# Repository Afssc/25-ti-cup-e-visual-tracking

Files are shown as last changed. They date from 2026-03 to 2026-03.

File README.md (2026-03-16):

# 2025 TI杯 E题｜云台视觉跟踪方案

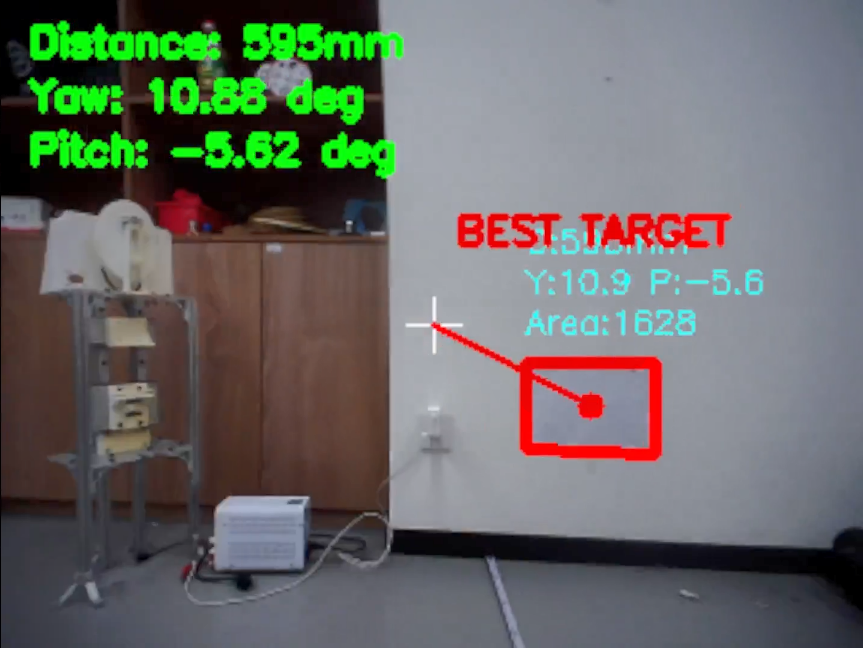
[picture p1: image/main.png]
系统主图


## 1. 系统概述

本项目面向 TI 杯 E 题视觉跟踪场景，采用“嵌入式控制 + 视觉闭环”的一体化方案：

- **主控平台**：Raspberry Pi 4B（树莓派 4B）
- **云台执行机构**：双轴结构，使用 **2 个张大头闭环 42 步进电机**
- **传动结构**：双轴 **4:1 同步带轮减速**（提升分辨率与稳定性）
- **人机交互**：4×4 矩阵按键
	- 外圈 12 个按键：用于方向/视角快速选择
	- 中间 4 个按键：用于赛题功能触发、调试功能、激光开关等

控制逻辑上，按键触发云台预置位或功能回调，视觉环路计算偏差角后驱动双轴步进修正，目标居中后执行激光动作。

---

## 2. 硬件接线说明

项目中接线定义可参考 [key_uart_led.py](key_uart_led.py) 与 [key_array.py](key_array.py)。

### 2.1 LED + 独立按键 + 串口（`key_uart_led.py`）

| 功能 | BCM引脚/设备 | 说明 |
|---|---|---|
| 激光/LED 控制 | GPIO17 | 输出，高电平点亮 |
| KEY1 | GPIO5 | 上拉输入，下降沿触发 |
| KEY2 | GPIO6 | 上拉输入，下降沿触发 |
| 电机串口 | `/dev/ttyUSB0` | 115200 波特率 |

`key_uart_led.py` 的流程为：KEY1 触发回零指令与状态确认，通过后点亮激光；KEY2 直接熄灭激光。

### 2.2 4×4 矩阵按键（`key_array.py`）

矩阵按键采用 8 根 GPIO：

- **行引脚**：GPIO18、23、24、25（输出）
- **列引脚**：GPIO12、16、20、21（输入上拉）

程序通过逐行拉低扫描列输入，带 50ms 消抖逻辑，按键触发后执行映射回调（预置方位、赛题流程、调试、关激光等）。

---

## 3. 视觉算法流程（`cv.py` 中 `cv_loop`）

视觉主流程是“检测矩形目标 → 估距 → 解算角度 → 云台修正 → 命中判定”的闭环控制。

### 3.1 图像预处理

1. 缩放
2. 灰度化 + 高斯滤波
3. 自适应阈值分割（二值化）
4. 提取外轮廓

### 3.2 候选目标筛选

对轮廓依次执行：

- 面积阈值过滤（去噪）
- 多边形逼近（保留 4 边形）
- 凸性判断 + 凸包面积比过滤（提升几何可信度）

### 3.3 中心、距离与角度计算

- **中心点**：优先使用四边形对角线交点法估计目标中心
- **距离估计**：基于两组平行边像素长度，结合目标真实尺寸与视场角，按相似几何计算距离
- **角度解算**：将像素偏差转换为 yaw / pitch 偏差，并乘以增益系数
- **误差补偿**：按距离区间对中心点作经验修正（主要是 y 向修正）

### 3.4 目标选择与控制输出

- 评分策略：综合考虑目标面积与离图像中心距离
- 选择最佳目标后输出 `yaw/pitch`，调用云台运动接口执行修正
- 若像素误差落入容差阈值，则判定对准并点亮激光

该流程在比赛场景下兼顾了识别稳定性与闭环响应速度。
由于角度近似关系，大角度偏差需修正两次，小角度一次到位

---

## 4. 效果展示

### 4.1 云台结构

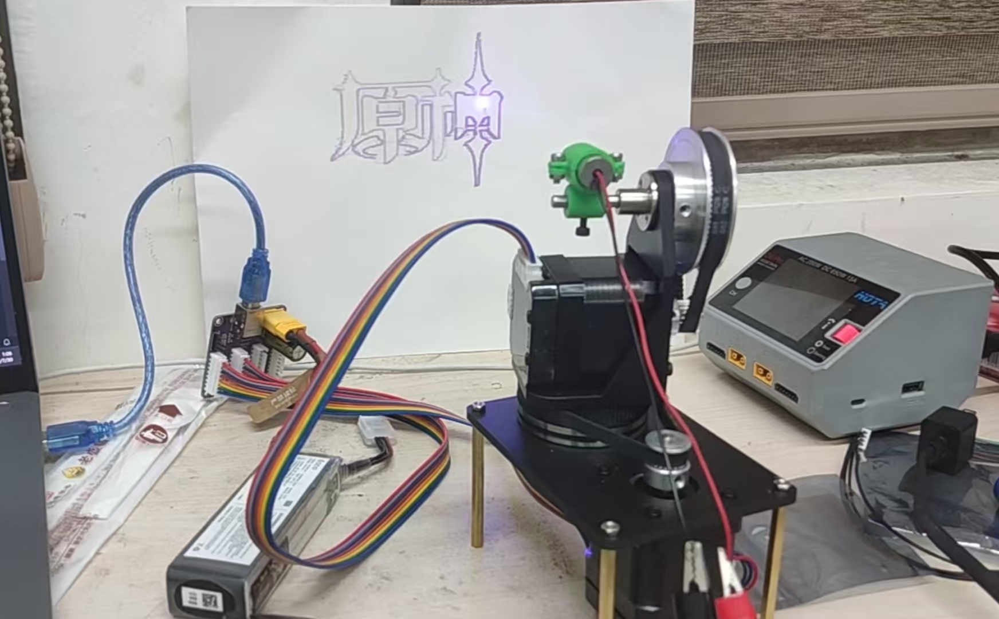
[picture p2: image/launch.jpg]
云台激光绘制展示


### 4.2 鲁棒性

鲁棒性展示

---

## 5. 项目结构与文件说明

```text
.
├── README.md
├── cv.py
├── key_array.py
├── key_callbacks.py
├── key_uart_led.py
├── lazer.py
├── zdt.py
├── image/
│   ├── main.png
│   ├── launch.jpg
│   └── robust.gif
├── stl/
│   ├── 带轮.stl
│   ├── 底板.stl
│   ├── 激光笔支架.stl
│   ├── 激光笔支架盖子.stl
│   ├── 转台.stl
│   └── 转接板.stl
└── test/
		├── a.ipynb
		├── cv.ipynb
		└── led_keys.py
```

### 文件职责说明

- `cv.py`：视觉检测与跟踪主循环（目标检测、估距、角度计算、闭环控制）
- `zdt.py`：张大头闭环步进电机串口协议封装与运动控制
- `lazer.py`：激光 GPIO 控制封装
- `key_array.py`：4×4 矩阵按键扫描、消抖与功能映射入口（主启动脚本）
- `key_callbacks.py`：按键回调函数集合（预置位、赛题动作、调试流程）
- `key_uart_led.py`：独立按键 + 串口状态确认 + 激光开关的接线与流程示例
- `image/`：README 展示图与动态效果图
- `stl/`：云台机械结构模型文件（3D 打印/结构复现）
- `test/`：项目早期验证脚本与实验 Notebook

---

## 6. 使用方式（开机自启动）

建议通过 `systemd` 将 `key_array.py` 配置为开机自动启动。

### 6.1 服务文件示例

在 `/etc/systemd/system/ti_gimbal.service` 新建：

```ini
[Unit]
Description=TI Cup Gimbal Vision Service
After=network.target

[Service]
Type=simple
User=pi
WorkingDirectory=/home/pi/2025TI杯-E题-云台视觉跟踪
ExecStart=/usr/bin/python3 /home/pi/2025TI杯-E题-云台视觉跟踪/key_array.py
Restart=always
RestartSec=2

[Install]
WantedBy=multi-user.target
```

> 若实际用户名、路径、Python 解释器路径不同，请按部署环境修改。

### 6.2 启用与验证

```bash
sudo systemctl daemon-reload
sudo systemctl enable ti_gimbal.service
sudo systemctl start ti_gimbal.service
sudo systemctl status ti_gimbal.service
```

### 6.3 常用维护命令

```bash
sudo systemctl restart ti_gimbal.service
sudo journalctl -u ti_gimbal.service -f
```

---

## 7. 说明

测评当天轮子电机故障，循线分没拿到，云台相关的分都拿了  
最终遗憾省二

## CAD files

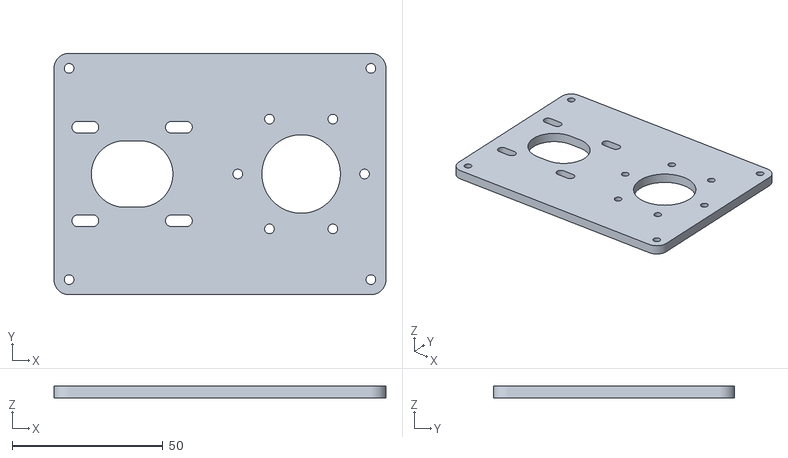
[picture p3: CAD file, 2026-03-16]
stl/底板.stl
110.0 x 80.0 x 4.00

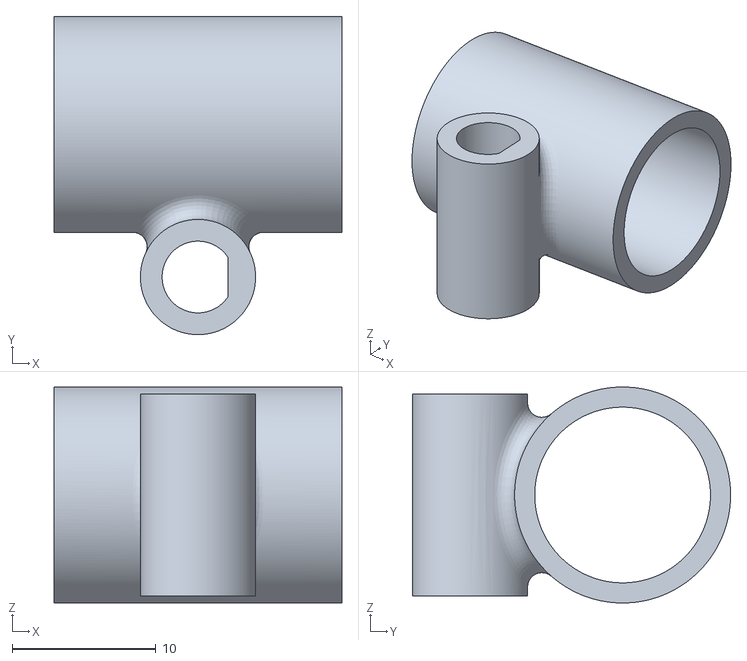
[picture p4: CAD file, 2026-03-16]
stl/激光笔支架.stl
20.0 x 22.1 x 15.0

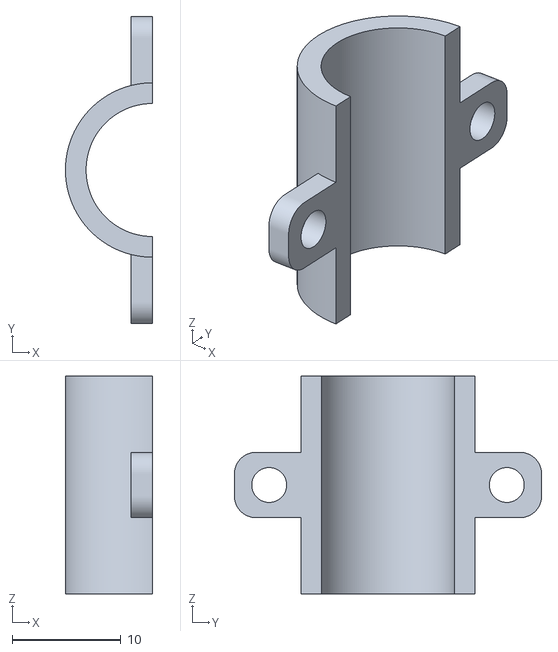
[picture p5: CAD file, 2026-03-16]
stl/激光笔支架盖子.stl
8.00 x 28.2 x 20.0

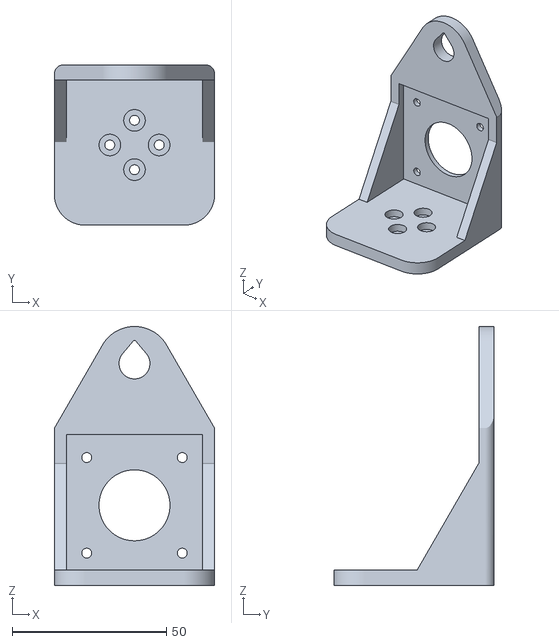
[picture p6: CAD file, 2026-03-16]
stl/转台.stl
52.0 x 52.0 x 84.0

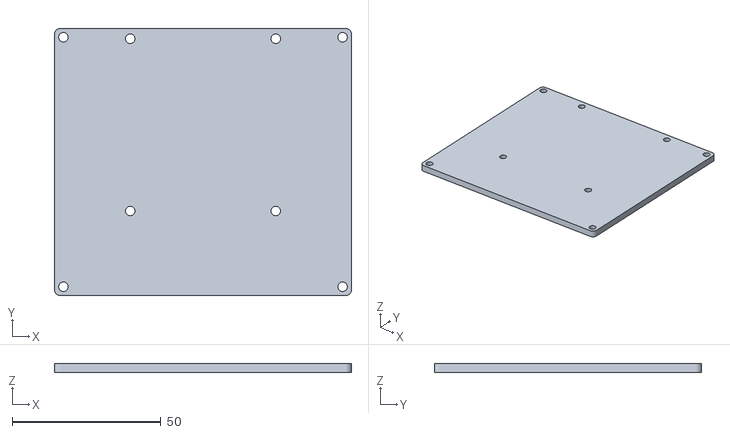
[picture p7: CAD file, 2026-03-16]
stl/转接板.stl
100.0 x 90.0 x 3.00

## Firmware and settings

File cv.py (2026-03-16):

import numpy as np
import cv2
import serial
from zdt import Zdt
from lazer import Lazer


# 暂时没有用到，可以用来把靶环给滤掉

# 云台配置参数
class GimbalConfig():
    def __init__(self,yp_move_callback,lazer_instance:Lazer):
        # 摄像头参数
        self.image_width = 320
        self.image_height = 240
        self.image_center_x = 151
        self.image_center_y = 131
        
        # 摄像头视野角度 (根据你的摄像头规格调整)
        self.camera_fov_horizontal = 90  # 水平视野角度（度）
        self.camera_fov_vertical = 64    # 垂直视野角度（度）
        
        # 已知矩形的实际尺寸 (单位：毫米，根据实际目标调整)
        self.real_rect_width = 315   # 实际矩形宽度
        self.real_rect_height = 225   # 实际矩形高度
        
        # 可以调的增益系数，主要是怕撞云台
        self.yaw_factor = 1.3
        self.pitch_factor = 1.3

        self.yp_move = yp_move_callback
        self.lazer = lazer_instance
        self.tolerance = 0.5
        self.keep_aim = False
        self.debug = False
    
def calculate_gimbal_angles(rect_center_x, rect_center_y, estimated_distance, config):
    """
    计算云台需要旋转的角度来瞄准矩形中心
    
    :param rect_center_x: 矩形中心x坐标
    :param rect_center_y: 矩形中心y坐标
    :param estimated_distance: 估计的目标距离 (毫米)    :param estimated_distance: 估计的目标距离
    :param config: 云台配置对象
    :return: (yaw_angle, pitch_angle) 云台需要旋转的角度（度）
    """
    # 计算像素偏差
    correction_x, correction_y = get_center_correction(estimated_distance)
    correction_x = int(np.round(correction_x,0))
    correction_y = int(np.round(correction_y,0))
    pixel_offset_x = rect_center_x - config.image_center_x + correction_x
    pixel_offset_y = config.image_center_y - rect_center_y + correction_y# 注意y轴方向
    
    # 使用三角函数和实际距离计算角度偏差
    # 首先计算像素偏移对应的实际物理距离
    # 根据相似三角形原理：physical_offset = pixel_offset * (2 * distance * tan(fov/2)) / image_size
    
    # 计算水平方向的实际物理偏移量 (毫米)
    physical_offset_x = pixel_offset_x * (2 * estimated_distance * np.tan(np.radians(config.camera_fov_horizontal / 2))) / config.image_width
    
    # 计算垂直方向的实际物理偏移量 (毫米)
    physical_offset_y = pixel_offset_y * (2 * estimated_distance * np.tan(np.radians(config.camera_fov_vertical / 2))) / config.image_height
    
    # 使用反正切函数计算角度偏差
    yaw_angle = np.degrees(np.arctan(physical_offset_x / estimated_distance))
    pitch_angle = np.degrees(np.arctan(physical_offset_y / estimated_distance))
    
    return yaw_angle, pitch_angle, pixel_offset_x, pixel_offset_y

# def calculate_gimbal_angles(rect_center_x, rect_center_y, estimated_distance, config):
#     """
#     计算云台需要旋转的角度来瞄准矩形中心
    
#     :param rect_center_x: 矩形中心x坐标
#     :param rect_center_y: 矩形中心y坐标
#     :param estimated_distance: 估计的目标距离
#     :param config: 云台配置对象
#     :return: (yaw_angle, pitch_angle) 云台需要旋转的角度（度）
#     """
#     # 计算像素偏差
#     pixel_offset_x = rect_center_x - config.image_center_x
#     pixel_offset_y = config.image_center_y - rect_center_y  # 注意y轴方向
    
#     # 转换为角度偏差
#     yaw_angle = pixel_offset_x / config.pixels_per_degree_x
#     pitch_angle = pixel_offset_y / config.pixels_per_degree_y
    
#     return yaw_angle, pitch_angle

def get_rectangle_center(contour):
    """
    获取矩形的中心点
    
    :param contour: 轮廓点
    :return: (center_x, center_y) 矩形中心坐标
    """
    # 方法1：使用轮廓的矩形边界框
    x, y, w, h = cv2.boundingRect(contour)
    center_x = x + w // 2
    center_y = y + h // 2
    
    # 方法2：使用轮廓的质心（更精确，但受线宽影响）
    # 注意：cv2.moments(contour) 只计算轮廓边界线的矩，不是填充区域的矩
    # 如果轮廓线宽不均匀，质心会偏向较粗的部分
    M = cv2.moments(contour)
    if M["m00"] != 0:
        cx = int(M["m10"] / M["m00"])
        cy = int(M["m01"] / M["m00"])
        return cx, cy
    else:
        return center_x, center_y

def get_rectangle_center_filled(contour, image_shape):
    """
    通过填充轮廓获取真正的几何中心（不受线宽影响）
    
    :param contour: 轮廓点
    :param image_shape: 图像尺寸 (height, width)
    :return: (center_x, center_y) 矩形中心坐标
    """
    # 创建空白掩码
    mask = np.zeros(image_shape, dtype=np.uint8)
    
    # 填充轮廓（修复参数类型）
    cv2.fillPoly(mask, [contour], (255,))
    
    # 计算填充区域的质心
    M = cv2.moments(mask)
    if M["m00"] != 0:
        cx = int(M["m10"] / M["m00"])
        cy = int(M["m01"] / M["m00"])
        return cx, cy
    else:
        # 降级到边界框方法
        x, y, w, h = cv2.boundingRect(contour)
        return x + w // 2, y + h // 2

def get_rectangle_center_diagonal(approx_contour):
    """
    通过计算四边形对角线交点来获取矩形中心
    
    :param approx_contour: 近似的四边形轮廓点 (4个点)
    :return: (center_x, center_y) 矩形中心坐标，如果无法计算则返回None
    """
    
    # 获取四个顶点坐标
    points = approx_contour.reshape(4, 2)
    
    # 找出对角顶点对
    # 方法：计算所有点对之间的距离，最长的两条距离对应两条对角线
    distances = []
    for i in range(4):
        for j in range(i + 1, 4):
            dist = np.sqrt((points[i][0] - points[j][0])**2 + (points[i][1] - points[j][1])**2)
            distances.append((dist, i, j))
    
    # 按距离排序，前两个最长的距离对应两条对角线
    distances.sort(key=lambda x: x[0], reverse=True)
    
    # 获取两条对角线的端点
    diagonal1_p1 = points[distances[0][1]]
    diagonal1_p2 = points[distances[0][2]]
    diagonal2_p1 = points[distances[1][1]]
    diagonal2_p2 = points[distances[1][2]]
    
    # 计算两条对角线的交点
    # 使用直线方程求交点
    def line_intersection(p1, p2, p3, p4):
        """
        计算由点p1-p2和p3-p4构成的两条直线的交点
        """
        x1, y1 = p1[0], p1[1]
        x2, y2 = p2[0], p2[1] 
        x3, y3 = p3[0], p3[1]
        x4, y4 = p4[0], p4[1]
        
        # 计算直线参数
        denom = (x1 - x2) * (y3 - y4) - (y1 - y2) * (x3 - x4)
        
        # 检查平行线
        if abs(denom) < 1e-10:
            return None
        
        # 计算交点
        t = ((x1 - x3) * (y3 - y4) - (y1 - y3) * (x3 - x4)) / denom
        
        intersection_x = x1 + t * (x2 - x1)
        intersection_y = y1 + t * (y2 - y1)
        
        return (int(intersection_x), int(intersection_y))
    
    # 计算对角线交点
    intersection = line_intersection(diagonal1_p1, diagonal1_p2, diagonal2_p1, diagonal2_p2)
    
    if intersection is None:
        # 如果无法计算交点，降级到边界框方法
        x, y, w, h = cv2.boundingRect(approx_contour)
        return (x + w // 2, y + h // 2)
    
    return intersection

def get_center_correction(distance_mm):
    """
    基于距离计算中心点矫正偏移量
    用于补偿由于镜头畸变、安装偏差等导致的系统性误差
    
    :param distance_mm: 目标距离 (毫米)
    :return: (correction_x, correction_y) 中心点矫正偏移量（像素）
    """
    # 可调节的矫正系数
    # 这些系数需要根据实际测试结果进行调整
    # x_slope = 0.000      # X方向斜率 (像素/毫米)
    # x_intercept = 0.0    # X方向截距 (像素)
    # y_slope = 0.05     # Y方向斜率 (像素/毫米) 
    # y_intercept = 0.0    # Y方向截距 (像素)
    
    # # 使用一次函数计算矫正量
    # # correction = slope * distance + intercept
    # correction_x = x_slope * distance_mm + x_intercept
    # correction_y = y_slope * distance_mm + y_intercept
    correction_x = 0
    # 
    if (distance_mm <600):
        correction_y = 6
    elif (600 <= distance_mm < 800):
        correction_y = 4
        
    elif (800 <= distance_mm < 1100):
        correction_y = 3
    elif (1100 <= distance_mm < 1500):
        correction_y = 1
    elif (1500 <= distance_mm < 1900):
        correction_y = 0
    else:
        correction_y = 0
 
    return correction_x, correction_y

print("云台配置和计算函数已加载完成！")

# 云台控制功能示例
    

def is_target_centered(pix_err_x, pix_err_y, tolerance=1.0):
    """
    检查目标是否已经居中
    
    :param yaw_angle: 当前yaw角度偏差
    :param pitch_angle: 当前pitch角度偏差
    :param tolerance: 容忍角度偏差（度）
    :return: True如果目标已居中
    """
    return abs(pix_err_x) < tolerance and abs(pix_err_y) < tolerance


print("云台控制功能已加载！")
# 改进的距离检测算法 - 基于平行边长度计算


def calculate_parallel_edges_length(approx_contour):
    """
    计算四边形中两对平行边的长度
    
    :param approx_contour: 近似的四边形轮廓点 (4个点)
    :return: (avg_width, avg_height) 平均宽度和高度（像素）
    """
    if len(approx_contour) != 4:
        return None, None
    
    # 获取四个顶点坐标
    points = approx_contour.reshape(4, 2)
    
    # 计算所有边的长度
    edge_lengths = []
    for i in range(4):
        p1 = points[i]
        p2 = points[(i + 1) % 4]
        length = np.sqrt((p2[0] - p1[0])**2 + (p2[1] - p1[1])**2)
        edge_lengths.append(length)
    
    # 找到对边（平行边）
    # 方法：计算所有边的向量，找到夹角最小的两对边
    vectors = []
    for i in range(4):
        p1 = points[i]
        p2 = points[(i + 1) % 4]
        vector = np.array([p2[0] - p1[0], p2[1] - p1[1]])
        vectors.append(vector)
    
    # 计算向量间的角度差异，找到平行边对
    def angle_between_vectors(v1, v2):
        """计算两个向量之间的角度"""
        cos_angle = np.dot(v1, v2) / (np.linalg.norm(v1) * np.linalg.norm(v2))
        cos_angle = np.clip(cos_angle, -1, 1)  # 防止数值误差
        return np.arccos(np.abs(cos_angle))  # 取绝对值，因为我们关心的是平行性
    
    # 寻找最平行的边对
    min_angle_pairs = []
    for i in range(4):
        for j in range(i + 2, 4):  # 只考虑对边
            if j == i + 2 or (i == 0 and j == 3):  # 确保是对边
                continue
            angle = angle_between_vectors(vectors[i], vectors[j])
            min_angle_pairs.append((i, j, angle, edge_lengths[i], edge_lengths[j]))
    
    # 简化：直接按照四边形的对边来计算
    # 边0和边2为一对，边1和边3为一对
    pair1_avg = (edge_lengths[0] + edge_lengths[2]) / 2  # 第一对对边的平均长度
    pair2_avg = (edge_lengths[1] + edge_lengths[3]) / 2  # 第二对对边的平均长度
    
    # 返回较长和较短的边作为宽度和高度
    if pair1_avg > pair2_avg:
        return pair1_avg, pair2_avg  # width, height
    else:
        return pair2_avg, pair1_avg  # width, height

def calculate_distance_from_parallel_edges(approx_contour, config):
    """
    基于平行边长度计算距离
    
    :param approx_contour: 近似的四边形轮廓点
    :param config: 云台配置对象
    :return: 估计的距离 (毫米)
    """
    avg_width, avg_height = calculate_parallel_edges_length(approx_contour)
    
    if avg_width is None or avg_height is None:
        return None
    
    # 使用相似三角形原理计算距离
    # distance = (real_size * image_size) / (pixel_size * 2 * tan(fov/2))
    
    # 计算基于宽度的距离
    distance_from_width = (config.real_rect_width * config.image_width) / \
                         (avg_width * 2 * np.tan(np.radians(config.camera_fov_horizontal / 2)))
    
    # 计算基于高度的距离
    distance_from_height = (config.real_rect_height * config.image_height) / \
                          (avg_height * 2 * np.tan(np.radians(config.camera_fov_vertical / 2)))
    
    # 取平均值作为最终距离估计
    estimated_distance = (distance_from_width + distance_from_height) / 2
    
    return estimated_distance

def draw_contour_edges_info(frame, approx_contour, rect_center):
    """
    在图像上绘制轮廓边长信息
    
    :param frame: 图像帧
    :param approx_contour: 近似轮廓
    :param rect_center: 矩形中心点
    """
    if len(approx_contour) != 4:
        return
    
    points = approx_contour.reshape(4, 2)
    avg_width, avg_height = calculate_parallel_edges_length(approx_contour)
    
    # if avg_width is not None and avg_height is not None:
    #     # 在矩形中心附近显示边长信息
    #     cv2.putText(frame, f'W:{avg_width:.1f}px', 
    #                (rect_center[0] - 30, rect_center[1] + 15), 
    #                cv2.FONT_HERSHEY_SIMPLEX, 0.4, (255, 0, 255), 1)
    #     cv2.putText(frame, f'H:{avg_height:.1f}px', 
    #                (rect_center[0] - 30, rect_center[1] + 30), 
    #                cv2.FONT_HERSHEY_SIMPLEX, 0.4, (255, 0, 255), 1)
    
    # 绘制每条边的长度
    for i in range(4):
        p1 = points[i]
        p2 = points[(i + 1) % 4]
        edge_length = np.sqrt((p2[0] - p1[0])**2 + (p2[1] - p1[1])**2)
        
        # 在边的中点显示长度
        mid_point = ((p1[0] + p2[0]) // 2, (p1[1] + p2[1]) // 2)
        cv2.putText(frame, f'{edge_length:.0f}', mid_point, 
                   cv2.FONT_HERSHEY_SIMPLEX, 0.3, (0, 255, 255), 1)

print("改进的距离检测算法已加载完成！")

def hls_filter(frame:np.ndarray,**kwargs) -> np.ndarray:
    """
    HLS颜色空间滤波
    :param frame: 输入图像
    :param kwargs: 可选参数，包含以下键值对：
        - h: H通道的阈值范围，格式为 (h_min, h_max)，默认 (0, 180)
        - l: L通道的阈值范围，格式为 (l_min, l_max)，默认 (0, 255)
        - s: S通道的阈值范围，格式为 (s_min, s_max)，默认 (0, 255)
    :return: 滤波后的二值图像
    """
    hls_frame = cv2.cvtColor(frame, cv2.COLOR_BGR2HLS)
    h_min, h_max = kwargs.get('h', (0, 180))
    l_min, l_max = kwargs.get('l', (0, 255))
    s_min, s_max = kwargs.get('s', (0, 255))

    if h_min < h_max:
        upper = np.array([h_max, l_max, s_max], dtype=np.uint8)
        lower = np.array([h_min, l_min, s_min], dtype=np.uint8)
        mask = cv2.inRange(hls_frame, lower, upper)
    else:
        upper1 = np.array([180, l_max, s_max], dtype=np.uint8)
        lower1 = np.array([h_min, l_min, s_min], dtype=np.uint8)
        upper2 = np.array([h_max, l_max, s_max], dtype=np.uint8)
        lower2 = np.array([0, l_min, s_min], dtype=np.uint8)
        mask1 = cv2.inRange(hls_frame, lower1, upper1)
        mask2 = cv2.inRange(hls_frame, lower2, upper2)
        mask = cv2.bitwise_or(mask1, mask2)

    return mask

def cv_loop(cap:cv2.VideoCapture,config: GimbalConfig):
    # 使用改进距离算法的完整检测循环
    # cap.set(cv2.CAP_PROP_AUTO_EXPOSURE, 0.25)  # Set auto exposure to manual mode
    # cap.set(cv2.CAP_PROP_EXPOSURE, -8)  # Set exposure value (adjust as needed)
    # cap.set(cv2.CAP_PROP_AUTO_EXPOSURE, 1)  # Set auto exposure to  mode
    debug = config.debug
    config.lazer.turn_off()

# 用于存储目标信息的变量
    target_found = False
    target_center = (0, 0)
    target_distance = 0
    yaw_angle = 0
    pitch_angle = 0
    pixel_err_x = np.inf
    pixel_err_y = np.inf

    while True:
        ret, frame = cap.read()
        if not ret:
            print("Failed to grab frame")
            break
        
        frame = cv2.resize(frame, (config.image_width, config.image_height))
        
        # 图像处理
        img = cv2.cvtColor(frame, cv2.COLOR_BGR2GRAY)
        img = cv2.GaussianBlur(img, (5, 5), 0)
        bimg = cv2.adaptiveThreshold(img, 255, cv2.ADAPTIVE_THRESH_GAUSSIAN_C, cv2.THRESH_BINARY_INV, 11, 7)
        
        # 矩形检测
        contours, _ = cv2.findContours(bimg, cv2.RETR_EXTERNAL, cv2.CHAIN_APPROX_SIMPLE)
        
        # 在原图上绘制检测到的矩形
        result_frame = frame.copy()
        # 绘制图像中心十字线
        if debug:
            cv2.line(result_frame, (config.image_center_x - 10, config.image_center_y), 
                    (config.image_center_x + 10, config.image_center_y), (255, 255, 255), 2)
            cv2.line(result_frame, (config.image_center_x, config.image_center_y - 10), 
                    (config.image_center_x, config.image_center_y + 10), (255, 255, 255), 2)
        
        target_found = False
        best_target = None
        best_score = 0
        
        for contour in contours:
            # 计算轮廓面积，过滤小的噪声
            area = cv2.contourArea(contour)
            if area <= 500:  # 可以调整这个阈值
                continue

            # 计算轮廓的近似多边形
            epsilon = 0.02 * cv2.arcLength(contour, True)
            approx = cv2.approxPolyDP(contour, epsilon, True)

            # 如果近似多边形有4个顶点，认为是矩形
            if len(approx) != 4:
                continue

            # 只保留凸多边形
            if not cv2.isContourConvex(approx):
                continue

            # 计算凸包面积与轮廓面积的比值来进一步验证凸性
            hull = cv2.convexHull(contour)
            hull_area = cv2.contourArea(hull)
            if hull_area <= 0:
                continue
            convexity_ratio = area / hull_area

            # 凸性比值应该接近1（凸多边形的面积与其凸包面积相等）
            if convexity_ratio <= 0.92:  # 调整阈值以过滤轻微的凹陷
                continue

            # 获取矩形信息 - 使用填充轮廓方法避免透视变形导致的线宽不均影响
            # rect_center_x, rect_center_y = get_rectangle_center_filled(contour, (config.image_height, config.image_width))
            rect_center_x, rect_center_y = get_rectangle_center_diagonal(approx)

            # 使用改进的距离计算算法
            estimated_distance = calculate_distance_from_parallel_edges(approx, config)
            if estimated_distance is None:  # 确保距离计算成功
                continue

            # 计算云台角度
            yaw, pitch, pixel_err_x, pixel_err_y = calculate_gimbal_angles(rect_center_x, rect_center_y, estimated_distance, config)

            yaw *= config.yaw_factor
            pitch *= config.pitch_factor

            # 计算平行边长度用于显示
            avg_width, avg_height = calculate_parallel_edges_length(approx)

            # 计算目标评分（距离图像中心越近分数越高，面积越大分数越高）
            center_distance = np.sqrt((rect_center_x - config.image_center_x)**2 + 
                                    (rect_center_y - config.image_center_y)**2)
            score = area / (center_distance + 1)  # 面积除以到中心的距离

            # 选择最佳目标
            if score > best_score:
                best_score = score
                best_target = {
                    'contour': contour,
                    'approx': approx,
                    'center': (rect_center_x, rect_center_y),
                    'area': area,
                    'distance': estimated_distance,
                    'yaw': yaw,
                    'pitch': pitch,
                    'convexity': convexity_ratio,
                    'avg_width': avg_width,
                    'avg_height': avg_height
                }
                target_found = True

            if debug:
                draw_contour_edges_info(result_frame, approx, (rect_center_x, rect_center_y))
                x, y, w, h = cv2.boundingRect(contour)
                cv2.putText(result_frame, f'D:{int(estimated_distance)}mm', (x, y-55), 
                        cv2.FONT_HERSHEY_SIMPLEX, 0.4, (255, 255, 0), 1)
                cv2.putText(result_frame, f'Y:{yaw:.1f} P:{pitch:.1f}', (x, y-40), 
                        cv2.FONT_HERSHEY_SIMPLEX, 0.4, (255, 255, 0), 1)
                cv2.putText(result_frame, f'Area:{int(area)}', (x, y-25), 
                        cv2.FONT_HERSHEY_SIMPLEX, 0.4, (255, 255, 0), 1)

        # 遍历结束后，best_target包含了得分最高的目标信息
        if target_found and best_target:
            # 更新全局目标信息
            target_center = best_target['center']
            target_distance = best_target['distance']
            yaw_angle = best_target['yaw']
            pitch_angle = best_target['pitch']
            
            if debug: 
                # 用红色突出显示最佳目标
                cv2.drawContours(result_frame, [best_target['approx']], -1, (0, 0, 255), 1)
                cv2.circle(result_frame, target_center, 1, (0, 0, 255), -1)
                
                # 绘制从图像中心到目标中心的连线
                cv2.line(result_frame, ( config.image_center_x, config.image_center_y), 
                        target_center, (0, 0, 255), 2)
                
                # 显示最佳目标的详细信息
                # cv2.putText(result_frame, f'TGT', (target_center[0]-50, target_center[1]-70), 
                #            cv2.FONT_HERSHEY_SIMPLEX, 0.5, (0, 0, 255), 2)
                
                # 在屏幕顶部显示云台控制信息
                cv2.putText(result_frame, f'Distance: {int(target_distance)}mm', (10, 20), 
                        cv2.FONT_HERSHEY_SIMPLEX, 0.5, (0, 255, 0), 2)
                cv2.putText(result_frame, f'Yaw: {yaw_angle:.2f} deg', (10, 40), 
                        cv2.FONT_HERSHEY_SIMPLEX, 0.5, (0, 255, 0), 2)
                cv2.putText(result_frame, f'Pitch: {pitch_angle:.2f} deg', (10, 60), 
                        cv2.FONT_HERSHEY_SIMPLEX, 0.5, (0, 255, 0), 2)
                
                # 显示平行边长度信息
                if best_target['avg_width'] and best_target['avg_height']:
                    cv2.putText(result_frame, f'AvgW: {best_target["avg_width"]:.1f}px', (10, 80), 
                            cv2.FONT_HERSHEY_SIMPLEX, 0.4, (255, 0, 255), 1)
                    cv2.putText(result_frame, f'AvgH: {best_target["avg_height"]:.1f}px', (10, 95), 
                            cv2.FONT_HERSHEY_SIMPLEX, 0.4, (255, 0, 255), 1)
        else:
            # 没有找到目标时的显示
            if debug:
                cv2.putText(result_frame, 'NO TARGET FOUND', (10, 30), 
                        cv2.FONT_HERSHEY_SIMPLEX, 0.6, (0, 0, 255), 2)
        
        # 显示图像
        if debug:
            cv2.imshow("Binary Image", bimg)
            cv2.imshow("Improved Gimbal Detection", result_frame)
        
        # 在控制台输出云台角度信息（可用于发送给云台控制器）
        if target_found and best_target and not config.debug:
            # print(f"Target found - Yaw: {yaw_angle:.2f}°, Pitch: {pitch_angle:.2f}°, Distance: {int(target_distance)}mm, "
            #     f"AvgW: {best_target['avg_width']:.1f}px, AvgH: {best_target['avg_height']:.1f}px")
            config.yp_move(yaw_angle,pitch_angle)
        
        # 按'q'退出，按's'保存当前帧，按'd'切换调试模式
        key = cv2.waitKey(1) & 0xFF
        if debug:
            config.lazer.turn_on()
            if key == ord('q'):
                cv2.destroyAllWindows()
                break
            elif key == ord('s') and target_found:
                config.yp_move(yaw_angle,pitch_angle) 
        else:
            if config.lazer.state != 0:
                continue
            if not is_target_centered(pixel_err_x,pixel_err_y,config.tolerance):
                continue
            config.lazer.turn_on()
            if not config.keep_aim:
                break

if __name__ == "__main__":
# 创建配置实例

    cap = cv2.VideoCapture(0)
    assert cap.isOpened()
    cap.set(cv2.CAP_PROP_AUTO_EXPOSURE, 0)  # Set auto exposure to manual mode
    cap.set(cv2.CAP_PROP_EXPOSURE, -8)  # Set exposure value (adjust as needed)
    cap.release()
    cap = cv2.VideoCapture(0)
    zdt = Zdt()
    lazer = Lazer()
    config = GimbalConfig(zdt.zdt_yp,lazer)
    config.debug = False  # 开启调试模式
    cv_loop(cap,config)

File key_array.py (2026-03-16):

#!/usr/bin/env python3
# key_array.py - 树莓派矩阵按键检测程序
import signal
import sys
import time
import cv2
import cv
from key_callbacks import *
import RPi.GPIO as GPIO

# GPIO配置
GPIO.setmode(GPIO.BCM)
GPIO.setwarnings(False)

# 引脚定义
ALL_PINS = [18, 23, 24, 25, 12, 16, 20, 21]
ROW_PINS = ALL_PINS[:4]  # 行引脚: [18, 23, 24, 25]
COL_PINS = ALL_PINS[4:]  # 列引脚: [12, 16, 20, 21]


# 按键状态记录
last_key_state = [[False for _ in range(4)] for _ in range(4)]
key_press_time = [[0 for _ in range(4)] for _ in range(4)]

KEY_MAP = []

# 防抖延时(毫秒)
DEBOUNCE_DELAY = 50

def setup_gpio():
    """初始化GPIO引脚"""
    # 设置行引脚为输出，初始为高电平
    for pin in ROW_PINS:
        GPIO.setup(pin, GPIO.OUT, initial=GPIO.HIGH)
    
    # 设置列引脚为输入，启用上拉电阻
    for pin in COL_PINS:
        GPIO.setup(pin, GPIO.IN, pull_up_down=GPIO.PUD_UP)
        
def key_map_init(zdt_instance,lazer_instance, cv_cap, cv_config:cv.GimbalConfig):
    """初始化按键映射"""
    # 按键映射，4x4矩阵
    global KEY_MAP
    yt = lambda angle: create_yaw_cv_function(angle,zdt_instance,cv_cap,cv_config) #太长了，写短
    lz_off = lazer_instance.turn_off  # 激光关闭函数引用
    # t2 = lambda:test2(zdt_instance,lazer_instance)  
    t2 = lambda:test2_close(cv_config=cv_config,cap=cv_cap)  
    cv_debug_on = lambda :debug_on(cv_cap,cv_config)

    KEY_MAP = [
        [yt(-45+90)  , yt(-18+90)  , yt(18+90)   , yt(45+90) ],
        [yt(-72+90)  , t2          , lz_off      , yt(72+90) ],
        [yt(-108+90) , lambda:None , cv_debug_on , yt(108+90)],
        [yt(-135+90) , yt(-162+90) , yt(162+90)  , yt(135+90)]
    ]


def scan_keys():
    """扫描矩阵按键"""
    pressed_keys = []
    
    for row in range(4):
        # 设置当前行为低电平
        GPIO.output(ROW_PINS[row], GPIO.LOW)
        time.sleep(0.001)  # 短暂延时确保电平稳定
        
        # 检查每一列
        for col in range(4):
            if GPIO.input(COL_PINS[col]) == GPIO.LOW:
                # 按键被按下
                current_time = int(time.time() * 1000)  # 转换为毫秒整数
                
                # 防抖处理
                if not last_key_state[row][col]:
                    # 新按下的按键
                    if current_time - key_press_time[row][col] > DEBOUNCE_DELAY:
                        last_key_state[row][col] = True
                        key_press_time[row][col] = current_time
                        pressed_keys.append((row, col, KEY_MAP[row][col]))
                        
            else:
                # 按键被释放
                if last_key_state[row][col]:
                    current_time = int(time.time() * 1000)  # 转换为毫秒整数
                    if current_time - key_press_time[row][col] > DEBOUNCE_DELAY:
                        last_key_state[row][col] = False
                        key_press_time[row][col] = current_time
        
        # 恢复当前行为高电平
        GPIO.output(ROW_PINS[row], GPIO.HIGH)
        
    return pressed_keys

def on_key_press(row, col, key_callback):
    """按键按下事件处理函数"""
    print(f"按键按下:  (位置: 行{row+1}, 列{col+1})")
    key_callback()  # 调用按键对应的函数
    
    # 在这里添加你的按键处理逻辑
    # if key_value.isdigit():
    #     print(f"数字键: {key_value}")
    # elif key_value in ['A', 'B', 'C', 'D']:
    #     print(f"功能键: {key_value}")
    # elif key_value == '*':
    #     print("星号键被按下")
    # elif key_value == '#':
    #     print("井号键被按下")

def cleanup_gpio():
    """清理GPIO资源"""
    print("清理GPIO资源...")
    GPIO.cleanup()

def signal_handler(sig, frame):
    """信号处理函数，用于优雅退出"""
    print("\n接收到退出信号，正在清理资源...")
    cleanup_gpio()
    sys.exit(0)

def main():
    """主函数"""
    print("矩阵按键检测程序启动...")
    print("按键映射:")
    for i, row in enumerate(KEY_MAP):
        print(f"第{i+1}行: {' '.join(row)}")
    print("按 Ctrl+C 退出程序\n")
    
    # 注册信号处理函数
    signal.signal(signal.SIGINT, signal_handler)
    signal.signal(signal.SIGTERM, signal_handler)
    
    # 初始化GPIO
    setup_gpio()
    zdt_instance = zdt.Zdt()
    lazer_instance = lazer.Lazer()
    gimbalcfg = cv.GimbalConfig(yp_move_callback=zdt_instance.zdt_yp,lazer_instance=lazer_instance)

    cap = cv2.VideoCapture(0)
    assert cap.isOpened()
    cap.set(cv2.CAP_PROP_AUTO_EXPOSURE, 0.25)  # Set auto exposure to manual mode
    cap.set(cv2.CAP_PROP_EXPOSURE, -8)  # Set exposure value (adjust as needed)
     
    key_map_init(zdt_instance, lazer_instance, cap, gimbalcfg)
    
    try:
        while True:
            # 扫描按键
            pressed_keys = scan_keys()
            
            # 处理按下的按键
            for row, col, key_callback in pressed_keys:
                on_key_press(row, col, key_callback)
            
            # 短暂延时，避免过度占用CPU
            time.sleep(0.01)
            
    except KeyboardInterrupt:
        pass
    finally:
        cleanup_gpio()

if __name__ == "__main__":
    main()
